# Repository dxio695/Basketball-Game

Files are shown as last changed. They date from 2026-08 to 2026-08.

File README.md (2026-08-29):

# Basketball Game

An ESP32-based arcade basketball game with automatic shot detection, score tracking, timed gameplay, and electromechanical control. Two IR sensors detect successful shots, two servos operate the moving mechanisms, and an SSD1309 OLED displays the timer and score.

The firmware is written in C++ using the Arduino framework and organized into separate modules for game logic, sensor input, servo control, and display output.

<p align="center">
  Completed dual-hoop arcade basketball game prototype
  &nbsp;&nbsp;&nbsp;
  Basketball game prototype during electronics integration and testing
</p>

<p align="center">
  <em>Completed prototype and electronics integration setup</em>
</p>

## Overview

The system is responsible for:

- **Game Control:** Manages the game state, 90-second timer, scoring, and round transitions.
- **Shot Detection:** Uses two IR sensors to detect balls passing through the hoops.
- **Motion Control:** Drives two servo-controlled moving mechanisms.
- **Display System:** Shows the welcome screen, countdown, remaining time, score, and final result.
- **Player Feedback:** Activates an LED and buzzer after each successful shot.
- **Hardware Testing:** Provides separate test programs for the sensors, servos, OLED, and buzzer.

The ESP32 acts as the central controller and coordinates all input, processing, and output devices.

## System Flow

<p align="center">
  System flow diagram showing initialization, round control, shot detection, scoring, feedback, and final results
</p>

<p align="center">
  <em>System flow from initialization to gameplay and final score display</em>
</p>

## System Operation

### Game Control

- Pressing the start button resets the score to **0** and begins a **90-second** round after the starting screen and **3–2–1** countdown.
- During gameplay, the controller updates all subsystems. When the timer reaches **0**, the game stops and the OLED displays the final score.

### Shot Detection

- Two IR sensors on **GPIO 19** and **GPIO 18** detect new **HIGH-to-LOW** transitions, preventing repeated counts while a beam remains blocked.
- A successful detection from either hoop adds **10 points**.

### Motion Control

- Two servos on **GPIO 32** and **GPIO 33** move from **0° to 180°**, reverse direction, and return to **0°**.
- Movement uses non-blocking `millis()` timing, allowing sensing and display updates to continue.

### Display and Feedback

- The OLED shows the welcome screen, countdown, remaining time, current score, and final result.
- Each successful shot activates the LED and buzzer for **800 ms**.

## Firmware Structure

```text
Firmware/
├── include/
│   └── PinMap.h
├── lib/
│   ├── Game/
│   │   ├── Game.cpp
│   │   └── Game.h
│   ├── IRSensorDriver/
│   │   ├── IRSensorDriver.cpp
│   │   └── IRSensorDriver.h
│   ├── OLEDDriver/
│   │   ├── OLEDDriver.cpp
│   │   └── OLEDDriver.h
│   └── ServoDriver/
│       ├── ServoDriver.cpp
│       └── ServoDriver.h
├── src/
│   ├── hardware_test/
│   │   ├── buzzer_test.cpp
│   │   ├── irsensor_test.cpp
│   │   ├── oled_test.cpp
│   │   └── servo_test.cpp
│   └── main.cpp
└── platformio.ini
```

The main firmware is divided into the following modules:

| Module | Responsibility |
|---|---|
| [`Game`](Firmware/lib/Game) | Coordinates the complete game state and hardware behaviour |
| [`IRSensorDriver`](Firmware/lib/IRSensorDriver) | Detects new IR beam interruptions |
| [`ServoDriver`](Firmware/lib/ServoDriver) | Controls non-blocking servo movement |
| [`OLEDDriver`](Firmware/lib/OLEDDriver) | Manages all OLED screens and display updates |
| [`PinMap.h`](Firmware/include/PinMap.h) | Stores the ESP32 pin assignments |
| [`main.cpp`](Firmware/src/main.cpp) | Initializes the system and starts or runs game rounds |
| [`hardware_test/`](Firmware/src/hardware_test) | Tests individual hardware components independently |

## Hardware Configuration

| Component | Connection | Purpose |
|---|---:|---|
| IR sensor 1 | GPIO 19 | Detects shots through the first hoop |
| IR sensor 2 | GPIO 18 | Detects shots through the second hoop |
| Servo 1 | GPIO 32 | Controls the first moving mechanism |
| Servo 2 | GPIO 33 | Controls the second moving mechanism |
| OLED SDA | GPIO 21 | I²C display data |
| OLED SCL | GPIO 22 | I²C display clock |
| LED | GPIO 26 | Visual shot feedback |
| Buzzer | GPIO 16 | Audio shot feedback |
| Start button | GPIO 27 | Starts a new game round |

## Mechanical Design

The physical structure was modelled in Fusion 360 and divided into four subassemblies so that each part could be developed, exported, and fabricated independently.

<p align="center">
  3D modelled Court
</p>

<p align="center">
  <em>Fusion 360 model of the complete basketball court assembly</em>
</p>

The mechanical design is organized as follows:

| Subassembly | Models | Responsibility |
|---|---|---|
| [`Basketball`](Enclosure/Basketball) | `Hoop`, `Pole` | Forms the scoring target and supports the hoop in position |
| [`Court`](Enclosure/Court) | `test2_court` | Defines the complete court structure and overall mechanical layout |
| [`Fan`](Enclosure/Fan) | `Fan Blade` | Provides the rotating element used by the ball-launching mechanism |
| [`Launcher`](Enclosure/Launcher) | `Base`, `Tube` | Supports the launcher and guides the ball through the mechanism |

Each model is provided in two formats:

- **Fusion 360 (`.f3d`):** Preserves the editable design history for further modification.
- **STEP (`.step`):** Provides a widely compatible model for other CAD and manufacturing software.

All mechanical design files are stored in the [`Enclosure`](Enclosure) directory.

## Bill of Materials

Component purchasing was documented in separate spreadsheets for AliExpress and DigiKey. Each sheet records the vendor, part details, quantity, unit price, stock status, delivery estimate, total cost in NZD, and purchase link.

| BOM | Components Covered |
|---|---|
| [AliExpress BOM](BOM/design_comp_bom_aliexpress.xlsx) | 2.42-inch OLED, I²S microphone, I²S audio amplifier, mini speaker, and MG90S 180°/360° servo options |
| [DigiKey BOM](BOM/design_comp_bom_digikey.xlsx) | SEN0503 IR break-beam sensors and WT-1205 buzzer |

The two spreadsheets provide the sourcing information used during prototype development. Reused, supplied, or structural items may not be included in these purchase requests.

## License

This project is available under the [MIT License](LICENSE).

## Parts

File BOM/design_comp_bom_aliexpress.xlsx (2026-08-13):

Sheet: Purchase Request
Item | Vendor Name | Vendor Part Number | Item Description | Currency (eg, USD, AUD, Euro) | Unit Price (Vendor Currency) | Exchange Rate | Quantity | Total Price (NZD) | In Stock | Estimated Delivery Time | Team Name | Link
4 | AliExpress |  | 2.42 inch 2.42" OLED Display | NZD | 15.51 | 1 | 1 | 15.51 | Yes | Jun 12 - 17 | dc-p1-team04-2026 | aliexpress OLED (https://www.aliexpress.com/item/4000002579405.html)
7 | AliExpress |  | MS3625 I2S Microphone Module | NZD | 3.61 | 1 | 1 | 3.61 | Yes | Jun 15 - 18 | dc-p1-team04-2026 | microphone module (https://www.aliexpress.com/item/1005009213592784.html)
8 | AliExpress |  | MAX98357A I2S Audio Amplifier | NZD | 3.2 | 1 | 1 | 3.2 | Yes | Jun 15 - 18 | dc-p1-team04-2026 | audio amplifier (https://www.aliexpress.com/item/1005007003802663.html)
9 | AliExpress |  | Mini Cavity Speaker | NZD | 4.88 | 1 | 1 | 4.88 | Yes | Jun 15 - 18 | dc-p1-team04-2026 | speaker (https://www.aliexpress.com/i/1005005699690954.html?gatewayAdapt=4itemAdapt)
10 | AliExpress |  | MG90S 9g Digital Mini Micro Servo 180/360 Degree (We want 360) | NZD | 5.51 | 1 | 2 | 11.02 | Yes | Jun 16 - 22 | dc-p1-team04-2026 | 360 degree servo (https://www.aliexpress.com/item/1005012075503634.html?src=google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)
11 | AliExpress |  | MG90S 9g Digital Mini Micro Servo 180/360 Degree (We want 180) | NZD | 5.51 | 1 | 3 | 16.53 | Yes | Jun 16 - 22 | dc-p1-team04-2026 | 180 degree servo (https://www.aliexpress.com/item/1005012075503634.html?src=google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)
12 |  |  |  |  |  | 0 |  | 0
13 |  |  |  |  |  | 0 |  | 0
14 |  |  |  |  |  | 0 |  | 0
15 |  |  |  |  |  | 0 |  | 0
16 |  |  |  |  |  | 0 |  | 0
17 |  |  |  |  |  | 0 |  | 0
18 |  |  |  |  |  | 0 |  | 0
19 |  |  |  |  |  | 0 |  | 0
20 |  |  |  |  |  | 0 |  | 0
Total (NZD) |  |  |  |  |  |  |  | $54.75

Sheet: Admin-Data
Suppliers
Digikey NZ
Element14 NZ
Jaycar NZ
RS Comp NZ
AliExpress
Ebay
Amazon AU
Currency | Exchange Rate
NZD | 1
AUD | 1.25
USD | 1.75
EUR | 2.05
CNY | 0.25

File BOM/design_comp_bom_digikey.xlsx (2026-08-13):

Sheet: Purchase Request
Item | Vendor Name | Vendor Part Number | Item Description | Currency (eg, USD, AUD, Euro) | Unit Price (Vendor Currency) | Exchange Rate | Quantity | Total Price (NZD) | In Stock | Estimated Delivery Time | Team Name | Link
1 | Digikey NZ | 1738-SEN0503-ND | SEN0503 IR break beam sensor | NZD | 9.453 | 1 | 5 | 47.265 | Yes | 2WK | dc-p1-team04-2026 | Digikey IR break beam sensor (https://www.digikey.co.nz/en/products/detail/dfrobot/SEN0503/15283061)
2 | Digikey NZ | 433-1028-ND | WT-1205 buzzer | NZD | 1.449 | 1 | 1 | 1.449 | Yes | 2WK | dc-p1-team04-2026 | buzzer (https://www.digikey.co.nz/en/products/detail/soberton-inc/WT-1205/479674)
3 |  |  |  |  |  | 0 |  | 0
6 |  |  |  |  |  | 0 |  | 0
10 |  |  |  |  |  | 0 |  | 0
11 |  |  |  |  |  | 0 |  | 0
12 |  |  |  |  |  | 0 |  | 0
13 |  |  |  |  |  | 0 |  | 0
14 |  |  |  |  |  | 0 |  | 0
15 |  |  |  |  |  | 0 |  | 0
16 |  |  |  |  |  | 0 |  | 0
17 |  |  |  |  |  | 0 |  | 0
18 |  |  |  |  |  | 0 |  | 0
19 |  |  |  |  |  | 0 |  | 0
20 |  |  |  |  |  | 0 |  | 0
Total (NZD) |  |  |  |  |  |  |  | $48.71

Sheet: Admin-Data
Suppliers
Digikey NZ
Element14 NZ
Jaycar NZ
RS Comp NZ
AliExpress
Ebay
Amazon AU
Currency | Exchange Rate
NZD | 1
AUD | 1.25
USD | 1.75
EUR | 2.05
CNY | 0.25

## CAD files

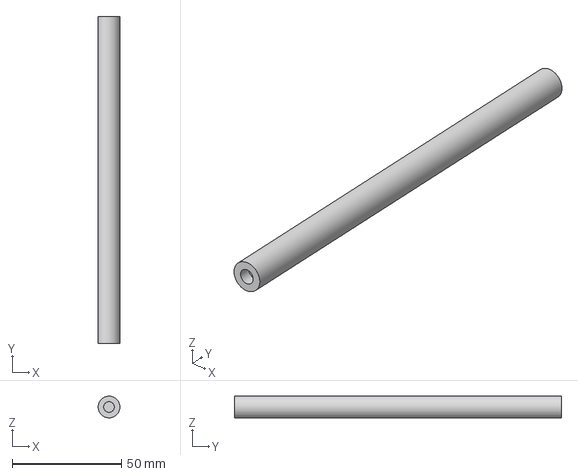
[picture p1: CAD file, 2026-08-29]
Enclosure/Basketball/Pole.step
9.99 x 150.0 x 10.00 mm

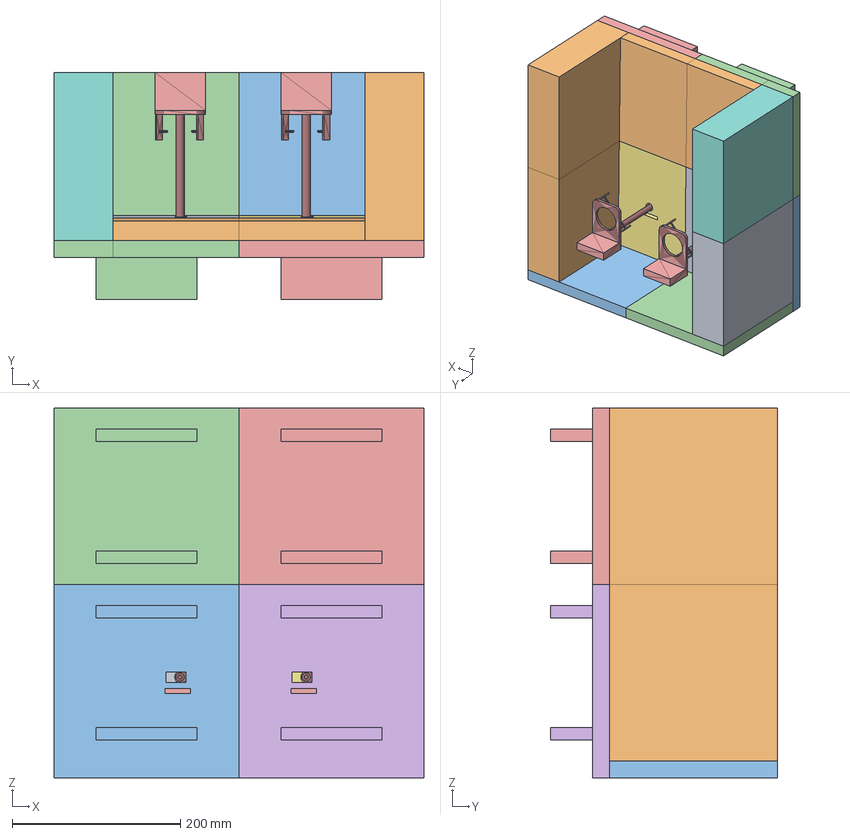
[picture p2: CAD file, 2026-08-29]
Enclosure/Court/test2_court.step
440.0 x 270.0 x 440.0 mm

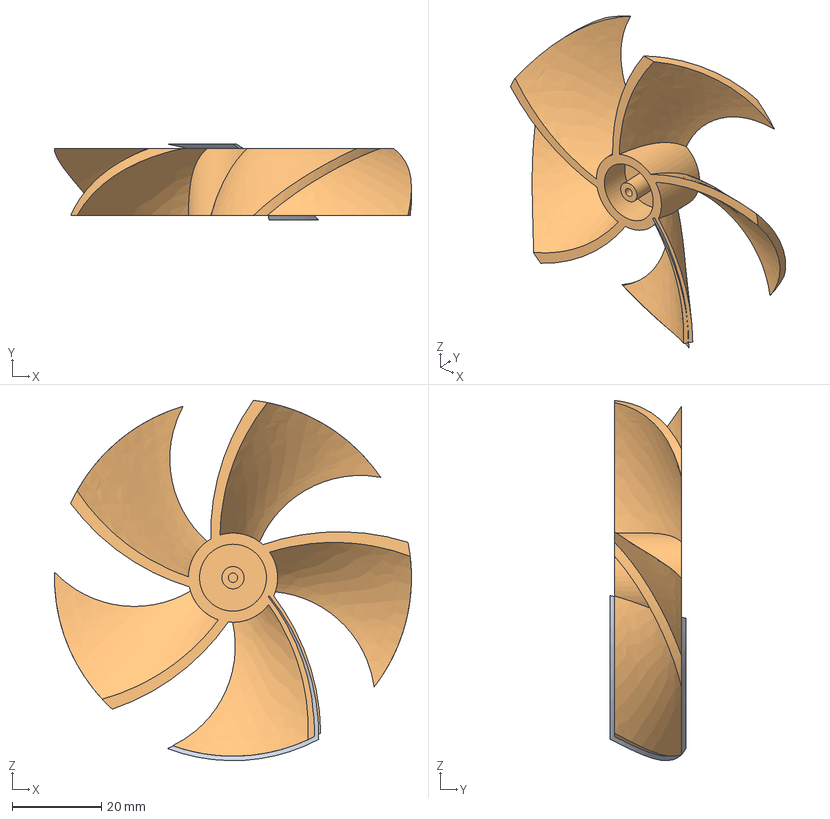
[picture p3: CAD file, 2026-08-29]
Enclosure/Fan/Fan Blade.step
80.0 x 17.0 x 80.7 mm

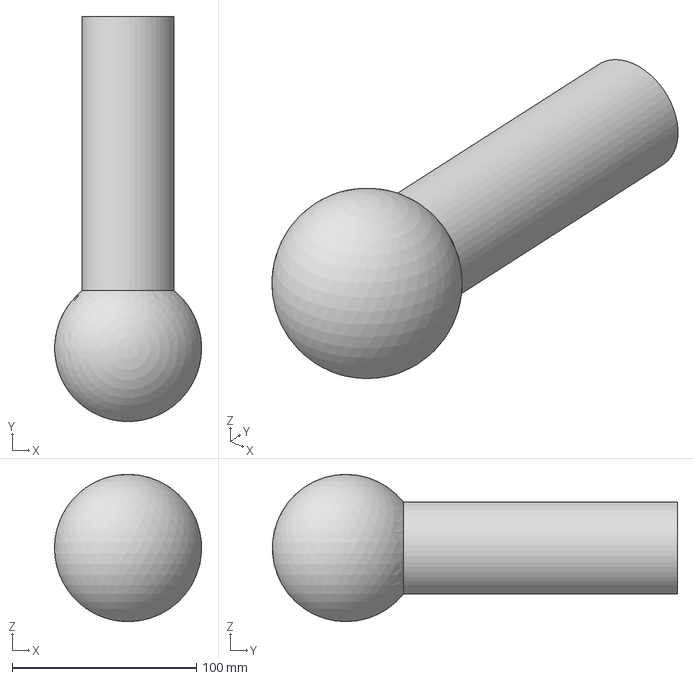
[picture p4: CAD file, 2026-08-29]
Enclosure/Launcher/Tube.step
79.9 x 219.9 x 80.0 mm

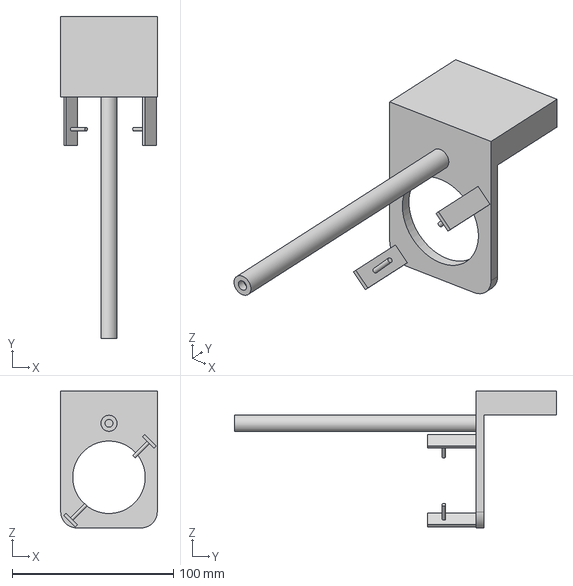
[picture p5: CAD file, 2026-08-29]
Enclosure/Basketball/Hoop.step
60.0 x 200.0 x 85.0 mm

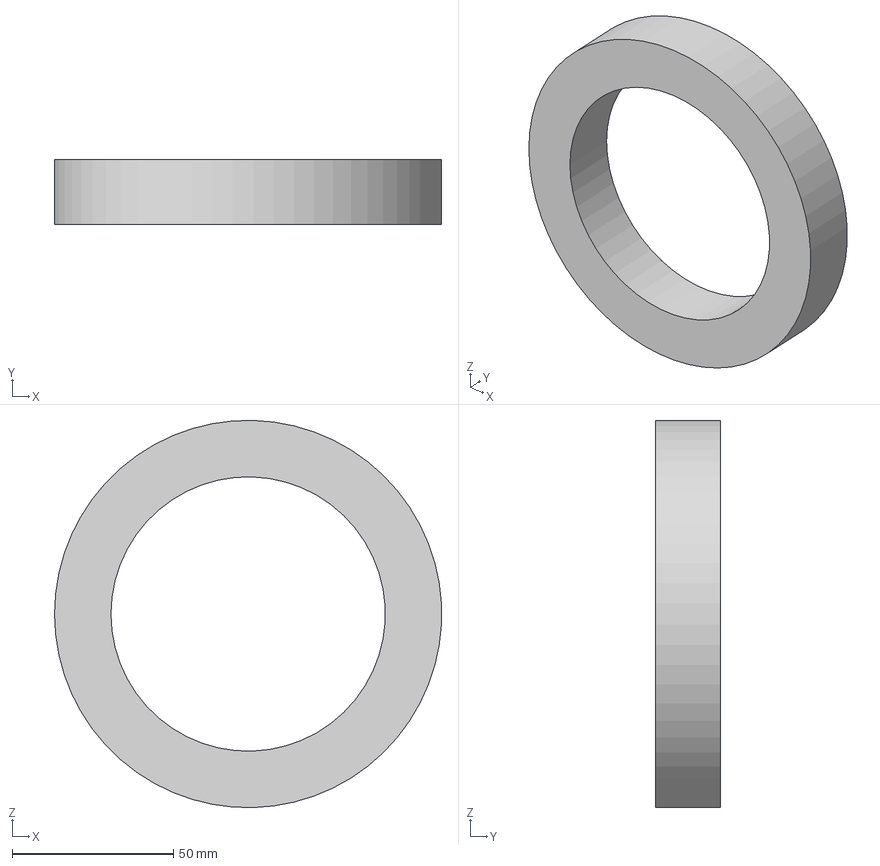
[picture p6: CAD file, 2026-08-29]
Enclosure/Launcher/Base.step
119.9 x 20.0 x 120.0 mm

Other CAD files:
Enclosure/Basketball/Hoop.f3d
Enclosure/Basketball/Pole.f3d
Enclosure/Court/test2_court.f3d
Enclosure/Fan/Fan Blade.f3d
Enclosure/Launcher/Base.f3d
Enclosure/Launcher/Tube.f3d

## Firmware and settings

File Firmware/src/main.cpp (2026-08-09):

#include <Game.h>
#include <Arduino.h>
#include <PinMap.h>

Game game;

bool lastButtonState = HIGH;

void setup() {
    Serial.begin(115200);
    pinMode(BUTTON_PIN, INPUT_PULLUP); // unpressed = HIGH, pressed = LOW
    game.initializeGame();
}

void loop() {
    int buttonState = digitalRead(BUTTON_PIN);
    bool buttonPressed = (buttonState == LOW && lastButtonState == HIGH); // falling edge
    lastButtonState = buttonState;


    if (buttonPressed && !game.isRunning()) {
        game.startRound();
    }

    game.runGame();
}

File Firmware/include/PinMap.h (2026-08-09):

#pragma once

constexpr int LED_PIN = 26;
constexpr int OLED_SCL_PIN = 22;
constexpr int OLED_SDA_PIN = 21;
constexpr int IR1_PIN = 19;
constexpr int IR2_PIN = 18;
constexpr int SERVO1_PIN = 32;
constexpr int SERVO2_PIN = 33;
constexpr int BUZZER_PIN = 16;
constexpr int BUTTON_PIN = 27;

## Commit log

2026-08-23 Add system flow diagram to README
2026-08-23 Add System Flow Diagram section to README
2026-08-29 Expand mechanical design and BOM documentation
